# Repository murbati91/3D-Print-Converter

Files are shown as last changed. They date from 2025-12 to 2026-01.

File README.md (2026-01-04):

# 3D Print Converter

Convert CAD files directly to G-code and stream to your 3D printer via WiFi.





## Overview

3D Print Converter is an open-source solution that bridges the gap between CAD design and 3D printing. Upload DWG, DXF, PDF, or SVG files through a web interface, and the system automatically converts them to G-code and streams directly to your 3D printer.

### Key Features

- **Web-Based Interface** - Access via `http://3dconverter.local` from any device
- **Multiple Input Formats** - DWG, DGN, DXF, PDF, SVG, DAT
- **Multiple Output Formats** - STL, OBJ, STEP, G-code, 3MF
- **Direct Printer Control** - Stream G-code via UART with real-time progress
- **Standalone Operation** - ESP32 controller with TFT display
- **Low Cost** - ~$12 BOM for the controller hardware

## Architecture

```
┌─────────────────┐     ┌─────────────────┐     ┌─────────────────┐
│   Web Browser   │────▶│  ESP32-S3       │────▶│   3D Printer    │
│   (Any Device)  │     │  Controller     │     │   (UART)        │
└─────────────────┘     └────────┬────────┘     └─────────────────┘
                                 │
                                 ▼
                        ┌─────────────────┐
                        │  Python Server  │
                        │  (Conversion)   │
                        └─────────────────┘
```

## Components

| Component | Description |
|---|---|
| **Firmware** | ESP32-S3 Arduino code with web server, SD card, TFT display |
| **Server** | Python FastAPI conversion engine |
| **Portable App** | Standalone Windows application |
| **Enclosure** | 3D printable case (OpenSCAD + STL) |

## Quick Start

### 1. Hardware Setup

**Required Components:**
- ESP32-S3-WROOM-1 module
- 2.4" TFT ILI9341 or 1.3" ST7789 display
- MicroSD card slot
- 5V power supply

**Wiring:**
| Function | GPIO |
|---|---|
| TFT CS | 5 |
| TFT DC | 2 |
| TFT RST | 4 |
| SD CS | 12 |
| Printer TX | 17 |
| Printer RX | 16 |

### 2. Flash Firmware

```bash
# Install PlatformIO
pip install platformio

# Build and upload
cd 3d-print-converter/firmware
pio run -t upload
```

### 3. Run Conversion Server

```bash
# Install dependencies
cd 3d-print-converter/software
pip install -r requirements.txt

# Start server
python server.py --host 0.0.0.0 --port 8000
```

### 4. Connect and Print

1. Connect to ESP32 WiFi AP (`3DConverter`) or configure your network
2. Open `http://3dconverter.local` in your browser
3. Upload a CAD file
4. Click Convert → Print

## Conversion Pipeline

```
Input File (DWG/PDF/DXF/SVG)
    │
    ▼
┌───────────────────────────────┐
│  Stage 1: Format Detection    │
└───────────────────────────────┘
    │
    ▼
┌───────────────────────────────┐
│  Stage 2: DXF Normalization   │
│  - ODA Converter (DWG/DGN)    │
│  - Inkscape (PDF→SVG→DXF)     │
│  - ezdxf (native DXF)         │
└───────────────────────────────┘
    │
    ▼
┌───────────────────────────────┐
│  Stage 3: 2D→3D Conversion    │
│  - Profile extrusion          │
│  - Polygon generation         │
└───────────────────────────────┘
    │
    ▼
┌───────────────────────────────┐
│  Stage 4: Mesh Processing     │
│  - Repair & validation        │
│  - Scale & center             │
└───────────────────────────────┘
    │
    ▼
┌───────────────────────────────┐
│  Stage 5: G-code Generation   │
│  - PrusaSlicer (primary)      │
│  - Built-in slicer (fallback) │
└───────────────────────────────┘
    │
    ▼
Output (G-code) → Printer
```

## API Reference

### Endpoints

| Method | Endpoint | Description |
|---|---|---|
| GET | `/status` | System health and tool availability |
| POST | `/api/convert` | Synchronous conversion (streaming response) |
| POST | `/api/convert/async` | Async conversion (returns job ID) |
| GET | `/api/jobs/{id}` | Check job status |
| GET | `/api/jobs/{id}/download` | Download converted file |
| GET | `/api/formats` | List supported formats |

### Example Request

```bash
curl -X POST http://localhost:8000/api/convert \
  -F "file=@drawing.dxf" \
  -F "output_format=gcode" \
  -F "extrusion_height=10" \
  -F "layer_height=0.2"
```

## Configuration

### Conversion Settings

| Parameter | Default | Description |
|---|---|---|
| `extrusion_height` | 10.0 mm | Height for 2D→3D extrusion |
| `scale_factor` | 1.0 | Model scaling |
| `layer_height` | 0.2 mm | Slicer layer height |
| `nozzle_diameter` | 0.4 mm | Printer nozzle size |
| `print_speed` | 50 mm/s | Print movement speed |
| `infill_percentage` | 20% | Interior fill density |
| `bed_size` | 220x220x250 | Print volume (mm) |

### External Tools

For full format support, install these optional tools:

| Tool | Purpose | Required For |
|---|---|---|
| [ODA File Converter](https://www.opendesign.com/guestfiles/oda_file_converter) | DWG/DGN support | .dwg, .dgn files |
| [Inkscape](https://inkscape.org/) | PDF conversion | .pdf files |
| [FreeCAD](https://www.freecad.org/) | STEP export | .step output |
| [PrusaSlicer](https://www.prusa3d.com/prusaslicer/) | G-code generation | Better slicing quality |

## Hardware BOM

| Part | Quantity | Est. Cost |
|---|---|---|
| ESP32-S3-WROOM-1 | 1 | $4.00 |
| 2.4" TFT ILI9341 | 1 | $4.00 |
| MicroSD Module | 1 | $1.00 |
| AMS1117 3.3V Regulator | 1 | $0.50 |
| USB-C Connector | 1 | $0.50 |
| PCB + Misc | 1 | $2.50 |
| **Total** | | **~$12.50** |

## Project Structure

```
3d-print-converter/
├── firmware/
│   ├── src/main.cpp          # ESP32 firmware (1300+ lines)
│   └── platformio.ini        # Build configuration
│
├── software/
│   ├── converter_engine.py   # Conversion pipeline
│   ├── server.py             # FastAPI REST server
│   └── requirements.txt      # Python dependencies
│
├── enclosure/
│   ├── *.scad                # OpenSCAD source files
│   └── stl/                  # Ready-to-print STL files
│
├── portable-app/             # Standalone Windows app
│
└── build-exe/                # Windows executable
    └── dist/3D-Print-Converter.exe
```

## Troubleshooting

### ESP32 not connecting to WiFi
- Check credentials in web config portal
- Try AP mode: connect to `3DConverter` network, access `192.168.4.1`

### Conversion fails
- Verify Python server is running on port 8000
- Check server logs for missing tools (ODA, Inkscape)
- Ensure input file is valid (try opening in original CAD software)

### Printer not responding
- Verify UART wiring (TX→RX, RX→TX)
- Check baud rate matches printer (default: 115200)
- Ensure printer firmware supports standard G-code (Marlin compatible)

## Contributing

Contributions are welcome! Please feel free to submit issues and pull requests.

1. Fork the repository
2. Create your feature branch (`git checkout -b feature/amazing-feature`)
3. Commit your changes (`git commit -m 'Add amazing feature'`)
4. Push to the branch (`git push origin feature/amazing-feature`)
5. Open a Pull Request

## License

This project is licensed under the MIT License - see the [LICENSE](LICENSE) file for details.

## Acknowledgments

- [ezdxf](https://github.com/mozman/ezdxf) - DXF file handling
- [trimesh](https://github.com/mikedh/trimesh) - 3D mesh processing
- [PrusaSlicer](https://github.com/prusa3d/PrusaSlicer) - G-code generation
- [TFT_eSPI](https://github.com/Bodmer/TFT_eSPI) - ESP32 display driver

---

Made with :gear: by [murbati91](https://github.com/murbati91)

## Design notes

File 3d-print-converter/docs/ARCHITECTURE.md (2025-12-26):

# CAD-to-3D Print Converter System
## Complete Open-Source Solution

### System Overview

```
┌─────────────────────────────────────────────────────────────────────────────┐
│                        CAD-to-3D Print Converter                             │
├─────────────────────────────────────────────────────────────────────────────┤
│                                                                              │
│  ┌──────────────┐    ┌──────────────────┐    ┌──────────────────────────┐   │
│  │ INPUT FILES  │    │  CONVERSION      │    │  OUTPUT                  │   │
│  │              │    │  PIPELINE        │    │                          │   │
│  │ • .dwg       │───►│                  │───►│ • .stl (mesh)            │   │
│  │ • .dgn       │    │ Python + FreeCAD │    │ • .gcode (printer ready) │   │
│  │ • .dxf       │    │ + ODA Converter  │    │ • .3mf (modern format)   │   │
│  │ • .pdf       │    │                  │    │                          │   │
│  │ • .dat       │    └────────┬─────────┘    └──────────────────────────┘   │
│  └──────────────┘             │                                              │
│                               │                                              │
│  ┌────────────────────────────▼─────────────────────────────────────────┐   │
│  │                     HARDWARE CONTROLLER                               │   │
│  │  ┌─────────────┐  ┌─────────────┐  ┌─────────────┐  ┌─────────────┐  │   │
│  │  │   ESP32-S3  │  │  SD Card    │  │  OLED/TFT   │  │  3D Printer │  │   │
│  │  │   Main MCU  │──│  Storage    │──│  Display    │──│  Interface  │  │   │
│  │  └─────────────┘  └─────────────┘  └─────────────┘  └─────────────┘  │   │
│  └──────────────────────────────────────────────────────────────────────┘   │
│                                                                              │
└─────────────────────────────────────────────────────────────────────────────┘
```

---

## Part 1: Software Components (All Open Source)

### Required Software Stack

| Component | Purpose | License |
|---|---|---|
| **Python 3.10+** | Main scripting | PSF |
| **FreeCAD** | CAD operations, 3D modeling | LGPL |
| **ODA File Converter** | DWG/DGN to DXF | Free (proprietary but free) |
| **Inkscape** | PDF to SVG/DXF | GPL |
| **OpenSCAD** | Parametric 3D from scripts | GPL |
| **PrusaSlicer/Cura** | STL to G-code | AGPL/LGPL |
| **ezdxf** | Python DXF library | MIT |
| **trimesh** | Python 3D mesh library | MIT |
| **numpy-stl** | STL file handling | BSD |

### Conversion Flow

```
                    ┌─────────────────────────────────────────┐
                    │         FILE TYPE DETECTION              │
                    └──────────────────┬──────────────────────┘
                                       │
          ┌────────────────┬───────────┼───────────┬────────────────┐
          ▼                ▼           ▼           ▼                ▼
    ┌──────────┐    ┌──────────┐ ┌──────────┐ ┌──────────┐   ┌──────────┐
    │   DWG    │    │   DGN    │ │   DXF    │ │   PDF    │   │   DAT    │
    └────┬─────┘    └────┬─────┘ └────┬─────┘ └────┬─────┘   └────┬─────┘
         │               │            │            │              │
         ▼               ▼            │            ▼              ▼
    ┌──────────┐    ┌──────────┐     │      ┌──────────┐   ┌──────────┐
    │   ODA    │    │   ODA    │     │      │ Inkscape │   │  Parser  │
    │Converter │    │Converter │     │      │ PDF→SVG  │   │ (custom) │
    └────┬─────┘    └────┬─────┘     │      └────┬─────┘   └────┬─────┘
         │               │            │            │              │
         └───────────────┴────────────┼────────────┴──────────────┘
                                      │
                                      ▼
                              ┌──────────────┐
                              │   DXF/SVG    │
                              │  Normalized  │
                              └──────┬───────┘
                                     │
                                     ▼
                              ┌──────────────┐
                              │   FreeCAD    │
                              │  Processing  │
                              │              │
                              │ • 2D → 3D    │
                              │ • Extrusion  │
                              │ • Healing    │
                              └──────┬───────┘
                                     │
                                     ▼
                              ┌──────────────┐
                              │  STL/STEP    │
                              │   Output     │
                              └──────┬───────┘
                                     │
                                     ▼
                              ┌──────────────┐
                              │  PrusaSlicer │
                              │  STL→G-code  │
                              └──────┬───────┘
                                     │
                                     ▼
                              ┌──────────────┐
                              │   G-CODE     │
                              │  (Print)     │
                              └──────────────┘
```

---

## Part 2: Hardware Design

### ESP32-S3 Controller Board Features

- **MCU**: ESP32-S3-WROOM-1 (dual-core, 240MHz, WiFi, BLE)
- **Display**: 2.4" TFT or 1.3" OLED
- **Storage**: MicroSD card slot
- **Connectivity**: 
  - USB-C (file upload + power)
  - WiFi (web interface)
  - UART (3D printer serial)
- **Controls**: Rotary encoder + buttons
- **Power**: 5V USB or 12V from printer PSU

### PCB Block Diagram

```
                          ┌─────────────────────────────────────┐
                          │         3D Print Controller         │
                          │              PCB v1.0               │
                          └─────────────────────────────────────┘
                                           │
    ┌──────────────────────────────────────┼──────────────────────────────────┐
    │                                      │                                   │
    │  ┌─────────────┐              ┌──────┴──────┐              ┌──────────┐ │
    │  │   USB-C     │              │             │              │  SD Card │ │
    │  │  Connector  │──────────────│  ESP32-S3   │──────────────│   Slot   │ │
    │  │  (CH340C)   │              │  WROOM-1    │              │          │ │
    │  └─────────────┘              │             │              └──────────┘ │
    │                               │  ┌───────┐  │                           │
    │  ┌─────────────┐              │  │ PSRAM │  │              ┌──────────┐ │
    │  │   5V/3.3V   │              │  │  8MB  │  │              │  TFT/    │ │
    │  │  Regulator  │──────────────│  └───────┘  │──────────────│  OLED    │ │
    │  │  (AMS1117)  │              │             │   SPI        │ Display  │ │
    │  └─────────────┘              └──────┬──────┘              └──────────┘ │
    │                                      │                                   │
    │  ┌─────────────┐              ┌──────┴──────┐              ┌──────────┐ │
    │  │   Rotary    │              │    UART     │              │  Status  │ │
    │  │   Encoder   │──────────────│   Header    │──────────────│   LEDs   │ │
    │  │  + Button   │   GPIO       │ (to Printer)│    GPIO      │  RGB x3  │ │
    │  └─────────────┘              └─────────────┘              └──────────┘ │
    │                                                                          │
    └──────────────────────────────────────────────────────────────────────────┘
```

### Pin Assignments

| Function | ESP32-S3 Pin | Notes |
|---|---|---|
| USB D+ | GPIO19 | Native USB |
| USB D- | GPIO20 | Native USB |
| SD_CMD | GPIO35 | SD Card |
| SD_CLK | GPIO36 | SD Card |
| SD_D0 | GPIO37 | SD Card |
| TFT_CS | GPIO10 | Display |
| TFT_DC | GPIO9 | Display |
| TFT_RST | GPIO8 | Display |
| TFT_MOSI | GPIO11 | SPI |
| TFT_SCLK | GPIO12 | SPI |
| UART_TX | GPIO43 | To Printer |
| UART_RX | GPIO44 | From Printer |
| ENC_A | GPIO4 | Rotary Encoder |
| ENC_B | GPIO5 | Rotary Encoder |
| ENC_SW | GPIO6 | Encoder Button |
| LED_R | GPIO38 | Status LED |
| LED_G | GPIO39 | Status LED |
| LED_B | GPIO40 | Status LED |

---

## Part 3: System Modes

### Mode 1: Standalone (ESP32 Only)
- Upload files via WiFi web interface
- Basic conversion (DXF → STL extrusion)
- Send G-code directly to printer

### Mode 2: With Companion Server (Raspberry Pi / PC)
- Full conversion pipeline
- Complex 3D operations
- Web dashboard
- Queue management

### Mode 3: Cloud Hybrid
- Heavy conversion on cloud/server
- ESP32 handles file transfer + printer control
- Perfect for your ICC integration

---

## Bill of Materials (BOM)

| Component | Qty | Est. Cost | Source |
|---|-----|---|---|
| ESP32-S3-WROOM-1-N8R8 | 1 | $4.50 | AliExpress/LCSC |
| 2.4" TFT ILI9341 | 1 | $3.00 | AliExpress |
| MicroSD Card Slot | 1 | $0.30 | LCSC |
| USB-C Connector | 1 | $0.20 | LCSC |
| AMS1117-3.3V | 1 | $0.10 | LCSC |
| CH340C (USB-UART) | 1 | $0.50 | LCSC |
| Rotary Encoder | 1 | $0.50 | AliExpress |
| RGB LEDs (WS2812B) | 3 | $0.30 | LCSC |
| Capacitors/Resistors | Kit | $1.00 | LCSC |
| PCB (JLCPCB) | 5 | $2.00 | JLCPCB |
| **Total** | | **~$12.50** | |

---

## Getting Started

1. Install software dependencies (see `software/requirements.txt`)
2. Run the conversion server
3. Flash ESP32 firmware
4. Connect to WiFi and access web interface
5. Upload files and print!

---

## License

MIT License - Use freely for personal and commercial projects.

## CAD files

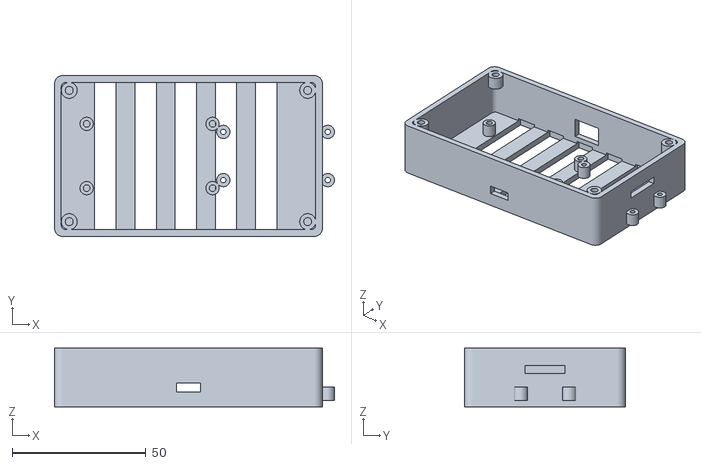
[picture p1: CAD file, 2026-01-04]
3d-print-converter/enclosure/stl/controller_base.stl
104.5 x 60.0 x 22.0

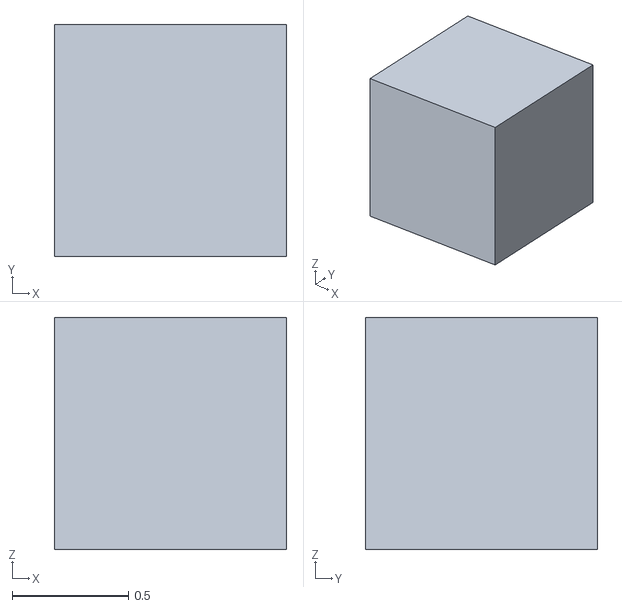
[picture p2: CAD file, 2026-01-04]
3d-print-converter/software/test_data/test_cube.stl
1.00 x 1.00 x 1.00

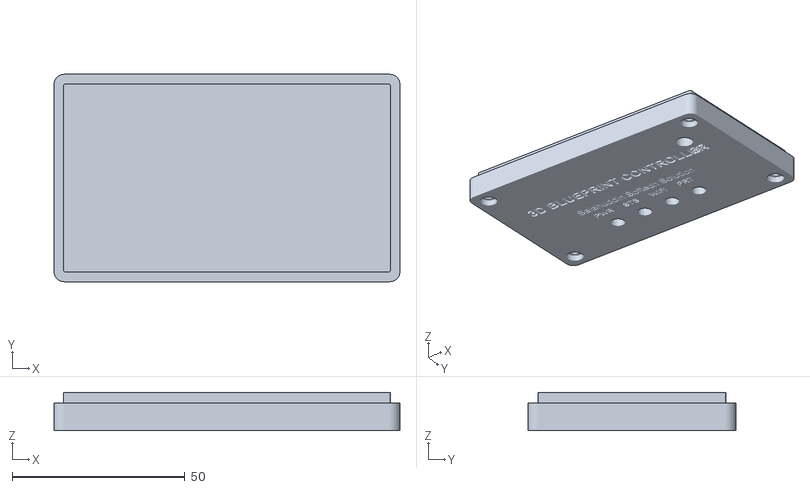
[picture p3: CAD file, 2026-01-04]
3d-print-converter/enclosure/stl/controller_lid.stl
100.0 x 60.0 x 11.0

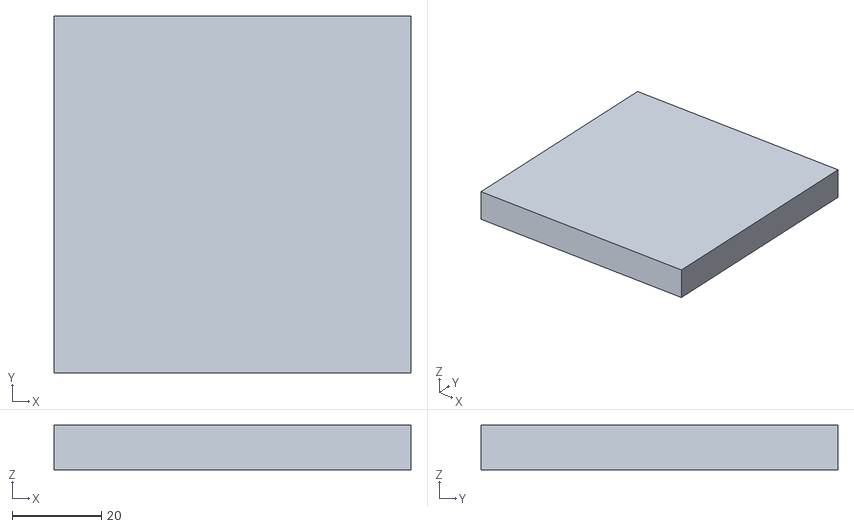
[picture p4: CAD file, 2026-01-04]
3d-print-converter/software/test_data/converted_square.stl
80.0 x 80.0 x 10.0

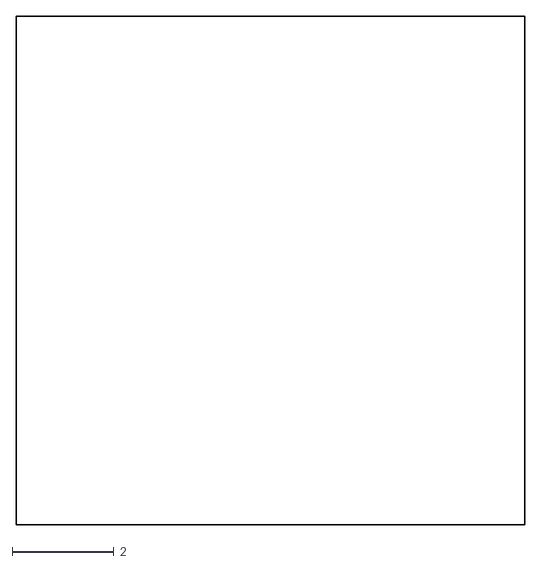
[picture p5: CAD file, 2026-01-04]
3d-print-converter/software/test_data/sample.dxf
10.0 x 10.0

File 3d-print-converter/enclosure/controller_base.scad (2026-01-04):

/*
 * 3D Blueprint Controller - BASE
 * Salahuddin Softech Solution
 *
 * Print this file for the enclosure base.
 * Export as STL: File > Export > Export as STL
 */

include <controller_enclosure.scad>

// Render base only
enclosure_base();

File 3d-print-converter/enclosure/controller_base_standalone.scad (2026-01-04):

/*
 * 3D Blueprint Controller - BASE (Standalone)
 * Salahuddin Softech Solution
 *
 * Print this file for the enclosure base.
 * Export as STL: File > Export > Export as STL
 */

// ==========================================
// PARAMETERS
// ==========================================

box_length = 100;
box_width = 60;
box_height = 30;
wall_thickness = 2.5;
corner_radius = 3;
base_height = 22;

esp32_length = 51;
esp32_width = 28;
esp32_standoff_height = 5;
esp32_hole_diameter = 2.5;

sd_module_length = 45;
sd_module_width = 24;
sd_module_standoff_height = 5;

usb_c_width = 9;
usb_c_height = 3.5;
sd_slot_width = 15;
sd_slot_height = 3;
uart_header_width = 12;
uart_header_height = 8;

screw_diameter = 3;
screw_head_diameter = 6;

// ==========================================
// MODULES
// ==========================================

module rounded_box(length, width, height, radius) {
    hull() {
        translate([radius, radius, 0])
            cylinder(r=radius, h=height, $fn=32);
        translate([length-radius, radius, 0])
            cylinder(r=radius, h=height, $fn=32);
        translate([radius, width-radius, 0])
            cylinder(r=radius, h=height, $fn=32);
        translate([length-radius, width-radius, 0])
            cylinder(r=radius, h=height, $fn=32);
    }
}

module screw_standoff(outer_d, inner_d, height) {
    difference() {
        cylinder(d=outer_d, h=height, $fn=24);
        cylinder(d=inner_d, h=height+1, $fn=24);
    }
}

// ==========================================
// BASE ENCLOSURE
// ==========================================

difference() {
    // Outer shell
    rounded_box(box_length, box_width, base_height, corner_radius);

    // Inner cavity
    translate([wall_thickness, wall_thickness, wall_thickness])
        rounded_box(
            box_length - 2*wall_thickness,
            box_width - 2*wall_thickness,
            base_height,
            corner_radius - wall_thickness/2
        );

    // USB-C port (front center)
    translate([box_length/2 - usb_c_width/2, -1, wall_thickness + 3])
        cube([usb_c_width, wall_thickness+2, usb_c_height]);

    // UART printer port (back)
    translate([box_length/2 - uart_header_width/2, box_width - wall_thickness - 1, wall_thickness + 3])
        cube([uart_header_width, wall_thickness+2, uart_header_height]);

    // SD card slot (right side)
    translate([box_length - wall_thickness - 1, box_width/2 - sd_slot_width/2, wall_thickness + esp32_standoff_height + 5])
        cube([wall_thickness+2, sd_slot_width, sd_slot_height]);

    // Ventilation slots (bottom)
    for (i = [0:4]) {
        translate([15 + i*15, wall_thickness/2, -1])
            cube([8, box_width - wall_thickness, wall_thickness+2]);
    }
}

// ESP32 mounting standoffs
esp32_x = 10;
esp32_y = (box_width - esp32_width) / 2;

standoff_positions = [
    [esp32_x + 2, esp32_y + 2],
    [esp32_x + esp32_length - 2, esp32_y + 2],
    [esp32_x + 2, esp32_y + esp32_width - 2],
    [esp32_x + esp32_length - 2, esp32_y + esp32_width - 2]
];

for (pos = standoff_positions) {
    translate([pos[0], pos[1], wall_thickness])
        screw_standoff(5, esp32_hole_diameter, esp32_standoff_height);
}

// SD module mounting standoffs
sd_x = 60;
sd_y = (box_width - sd_module_width) / 2;

sd_standoff_positions = [
    [sd_x + 3, sd_y + 3],
    [sd_x + sd_module_length - 3, sd_y + 3],
    [sd_x + 3, sd_y + sd_module_width - 3],
    [sd_x + sd_module_length - 3, sd_y + sd_module_width - 3]
];

for (pos = sd_standoff_positions) {
    translate([pos[0], pos[1], wall_thickness])
        screw_standoff(5, 2, sd_module_standoff_height);
}

// Lid mounting posts
lid_post_positions = [
    [wall_thickness + 3, wall_thickness + 3],
    [box_length - wall_thickness - 3, wall_thickness + 3],
    [wall_thickness + 3, box_width - wall_thickness - 3],
    [box_length - wall_thickness - 3, box_width - wall_thickness - 3]
];

for (pos = lid_post_positions) {
    translate([pos[0], pos[1], base_height - 5])
        screw_standoff(screw_head_diameter, screw_diameter, 5);
}

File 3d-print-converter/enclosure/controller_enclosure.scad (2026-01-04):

/*
 * 3D Blueprint Controller Enclosure
 * Salahuddin Softech Solution
 *
 * Housing for ESP32 + SD Card Module
 * Designed for FDM 3D printing (PLA/PETG)
 *
 * Print Settings:
 * - Layer Height: 0.2mm
 * - Infill: 20%
 * - Supports: Not required
 * - Walls: 3 perimeters
 */

// ==========================================
// PARAMETERS - Adjust as needed
// ==========================================

// Overall dimensions (mm)
box_length = 100;      // X dimension
box_width = 60;        // Y dimension
box_height = 30;       // Z dimension (base + lid)
wall_thickness = 2.5;
corner_radius = 3;

// Base/Lid split
base_height = 22;
lid_height = 8;

// ESP32 dimensions (ESP32-WROOM-32 DevKit)
esp32_length = 51;
esp32_width = 28;
esp32_standoff_height = 5;
esp32_hole_diameter = 2.5;

// SD Card module dimensions
sd_module_length = 45;
sd_module_width = 24;
sd_module_standoff_height = 5;

// LED hole dimensions
led_diameter = 5;  // 5mm LEDs
led_spacing = 12;
led_count = 4;

// Port dimensions
usb_c_width = 9;
usb_c_height = 3.5;
sd_slot_width = 15;
sd_slot_height = 3;
uart_header_width = 12;
uart_header_height = 8;

// Screw hole dimensions
screw_diameter = 3;
screw_head_diameter = 6;
screw_standoff_height = 3;

// Text emboss depth
text_depth = 0.8;

// Tolerance for fit
tolerance = 0.3;

// ==========================================
// MODULES
// ==========================================

// Rounded box module
module rounded_box(length, width, height, radius) {
    hull() {
        translate([radius, radius, 0])
            cylinder(r=radius, h=height, $fn=32);
        translate([length-radius, radius, 0])
            cylinder(r=radius, h=height, $fn=32);
        translate([radius, width-radius, 0])
            cylinder(r=radius, h=height, $fn=32);
        translate([length-radius, width-radius, 0])
            cylinder(r=radius, h=height, $fn=32);
    }
}

// Screw standoff
module screw_standoff(outer_d, inner_d, height) {
    difference() {
        cylinder(d=outer_d, h=height, $fn=24);
        cylinder(d=inner_d, h=height+1, $fn=24);
    }
}

// LED holder
module led_holder(diameter, depth) {
    union() {
        // Main LED hole
        cylinder(d=diameter, h=depth+1, $fn=24);
        // Flange for LED retention
        translate([0, 0, depth-1])
            cylinder(d=diameter+2, h=2, $fn=24);
    }
}

// ==========================================
// BASE ENCLOSURE
// ==========================================

module enclosure_base() {
    difference() {
        // Outer shell
        rounded_box(box_length, box_width, base_height, corner_radius);

        // Inner cavity
        translate([wall_thickness, wall_thickness, wall_thickness])
            rounded_box(
                box_length - 2*wall_thickness,
                box_width - 2*wall_thickness,
                base_height,
                corner_radius - wall_thickness/2
            );

        // USB-C port (front center)
        translate([box_length/2 - usb_c_width/2, -1, wall_thickness + 3])
            cube([usb_c_width, wall_thickness+2, usb_c_height]);

        // UART printer port (back)
        translate([box_length/2 - uart_header_width/2, box_width - wall_thickness - 1, wall_thickness + 3])
            cube([uart_header_width, wall_thickness+2, uart_header_height]);

        // SD card slot (right side)
        translate([box_length - wall_thickness - 1, box_width/2 - sd_slot_width/2, wall_thickness + esp32_standoff_height + 5])
            cube([wall_thickness+2, sd_slot_width, sd_slot_height]);

        // Ventilation slots (bottom)
        for (i = [0:4]) {
            translate([15 + i*15, wall_thickness/2, -1])
                cube([8, box_width - wall_thickness, wall_thickness+2]);
        }
    }

    // ESP32 mounting standoffs (4 corners)
    esp32_x = 10;
    esp32_y = (box_width - esp32_width) / 2;

    // Standoff positions for ESP32
    standoff_positions = [
        [esp32_x + 2, esp32_y + 2],
        [esp32_x + esp32_length - 2, esp32_y + 2],
        [esp32_x + 2, esp32_y + esp32_width - 2],
        [esp32_x + esp32_length - 2, esp32_y + esp32_width - 2]
    ];

    for (pos = standoff_positions) {
        translate([pos[0], pos[1], wall_thickness])
            screw_standoff(5, esp32_hole_diameter, esp32_standoff_height);
    }

    // SD module mounting standoffs
    sd_x = 60;
    sd_y = (box_width - sd_module_width) / 2;

    sd_standoff_positions = [
        [sd_x + 3, sd_y + 3],
        [sd_x + sd_module_length - 3, sd_y + 3],
        [sd_x + 3, sd_y + sd_module_width - 3],
        [sd_x + sd_module_length - 3, sd_y + sd_module_width - 3]
    ];

    for (pos = sd_standoff_positions) {
        translate([pos[0], pos[1], wall_thickness])
            screw_standoff(5, 2, sd_module_standoff_height);
    }

    // Lid mounting posts (4 corners)
    lid_post_positions = [
        [wall_thickness + 3, wall_thickness + 3],
        [box_length - wall_thickness - 3, wall_thickness + 3],
        [wall_thickness + 3, box_width - wall_thickness - 3],
        [box_length - wall_thickness - 3, box_width - wall_thickness - 3]
    ];

    for (pos = lid_post_positions) {
        translate([pos[0], pos[1], base_height - 5])
            screw_standoff(screw_head_diameter, screw_diameter, 5);
    }
}

// ==========================================
// LID
// ==========================================

module enclosure_lid() {
    difference() {
        union() {
            // Main lid body
            rounded_box(box_length, box_width, lid_height, corner_radius);

            // Inner lip for secure fit
            translate([wall_thickness + tolerance, wall_thickness + tolerance, -3])
                rounded_box(
                    box_length - 2*(wall_thickness + tolerance),
                    box_width - 2*(wall_thickness + tolerance),
                    3,
                    corner_radius - wall_thickness
                );
        }

        // LED holes (4 LEDs in a row)
        led_start_x = (box_length - (led_count-1) * led_spacing) / 2;
        led_y = 15;

        for (i = [0:led_count-1]) {
            translate([led_start_x + i * led_spacing, led_y, -1])
                led_holder(led_diameter, lid_height + 2);
        }

        // Reset button hole
        translate([box_length - 15, box_width - 15, -1])
            cylinder(d=6, h=lid_height + 2, $fn=24);

        // Screw holes for lid attachment
        lid_post_positions = [
            [wall_thickness + 3, wall_thickness + 3],
            [box_length - wall_thickness - 3, wall_thickness + 3],
            [wall_thickness + 3, box_width - wall_thickness - 3],
            [box_length - wall_thickness - 3, box_width - wall_thickness - 3]
        ];

        for (pos = lid_post_positions) {
            translate([pos[0], pos[1], -1])
                cylinder(d=screw_diameter + 0.5, h=lid_height + 5, $fn=24);
            // Countersink for screw head
            translate([pos[0], pos[1], lid_height - 2])
                cylinder(d=screw_head_diameter, h=3, $fn=24);
        }

        // Branding text emboss (top surface)
        translate([box_length/2, box_width/2 + 8, lid_height - text_depth])
            linear_extrude(text_depth + 1)
                text("3D BLUEPRINT CONTROLLER",
                     size=4,
                     font="Arial:style=Bold",
                     halign="center",
                     valign="center");

        translate([box_length/2, box_width/2 - 2, lid_height - text_depth])
            linear_extrude(text_depth + 1)
                text("Salahuddin Softech Solution",
                     size=3,
                     font="Arial",
                     halign="center",
                     valign="center");

        // LED labels
        led_labels = ["PWR", "STS", "WiFi", "PRT"];
        for (i = [0:led_count-1]) {
            translate([led_start_x + i * led_spacing, led_y + 8, lid_height - text_depth])
                linear_extrude(text_depth + 1)
                    text(led_labels[i],
                         size=2.5,
                         font="Arial:style=Bold",
                         halign="center",
                         valign="center");
        }

        // Reset label
        translate([box_length - 15, box_width - 22, lid_height - text_depth])
            linear_extrude(text_depth + 1)
                text("RST",
                     size=2.5,
                     font="Arial:style=Bold",
                     halign="center",
                     valign="center");
    }
}

// ==========================================
// PORT LABELS (for base)
// ==========================================

module port_labels() {
    // USB-C label
    translate([box_length/2, -0.5, base_height - 5])
        rotate([90, 0, 0])
            linear_extrude(1)
                text("USB-C", size=3, font="Arial:style=Bold", halign="center");
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

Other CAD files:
3d-print-converter/enclosure/controller_lid.scad

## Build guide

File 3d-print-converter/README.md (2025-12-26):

# 🖨️ CAD-to-3D Print Converter

> **Open-source solution for converting DWG, DGN, DXF, PDF to 3D printable formats**





## 🎯 Features

- **Multi-format support**: DWG, DGN, DXF, PDF, DAT, SVG
- **Output formats**: STL, OBJ, STEP, G-code, 3MF
- **Hardware controller**: ESP32-S3 based PCB design
- **Web interface**: Upload files via WiFi
- **Direct printing**: Stream G-code to printer
- **100% Open Source**: MIT licensed

## 📁 Project Structure

```
3d-print-converter/
├── software/              # Python conversion engine
│   ├── converter_engine.py    # Main conversion library
│   ├── server.py             # FastAPI REST server
│   └── requirements.txt      # Python dependencies
│
├── firmware/              # ESP32-S3 firmware
│   ├── src/main.cpp          # Main firmware code
│   └── platformio.ini        # PlatformIO config
│
├── hardware/              # PCB design files
│   └── 3d_print_controller.kicad_sch
│
├── docs/                  # Documentation
│   └── ARCHITECTURE.md       # System architecture
│
├── install.sh            # Installation script
└── README.md             # This file
```

## 🚀 Quick Start

### Option 1: Software Only (PC/Server)

```bash
# Clone the repository
git clone https://github.com/your-repo/3d-print-converter.git
cd 3d-print-converter

# Run installation script
chmod +x install.sh
./install.sh

# Start the server
source venv/bin/activate
python software/server.py
```

Access the API at: `http://localhost:8000`

### Option 2: Full System (ESP32 + Server)

1. **Install software** (as above)
2. **Flash ESP32 firmware**:
   ```bash
   cd firmware
   pio run -t upload
   ```
3. **Configure WiFi** via AP mode (192.168.4.1)
4. **Set companion server URL** in web interface

## 📖 API Usage

### Convert a File

```bash
# Single file conversion
curl -X POST "http://localhost:8000/api/convert" \
  -F "file=@drawing.dwg" \
  -o output.gcode

# With parameters
curl -X POST "http://localhost:8000/api/convert?output_format=stl&extrusion_height=5" \
  -F "file=@drawing.dxf" \
  -o output.stl
```

### Python Client

```python
import requests

# Convert file
with open('drawing.dwg', 'rb') as f:
    response = requests.post(
        'http://localhost:8000/api/convert',
        files={'file': f},
        params={'output_format': 'gcode'}
    )

# Save result
with open('output.gcode', 'wb') as f:
    f.write(response.content)
```

## 🔧 Hardware Build

### Bill of Materials (~$12.50)

| Component | Qty | Est. Cost |
|---|-----|---|
| ESP32-S3-WROOM-1-N8R8 | 1 | $4.50 |
| 2.4" TFT ILI9341 | 1 | $3.00 |
| MicroSD Card Slot | 1 | $0.30 |
| USB-C Connector | 1 | $0.20 |
| AMS1117-3.3V | 1 | $0.10 |
| CH340C | 1 | $0.50 |
| Rotary Encoder | 1 | $0.50 |
| Misc (caps, resistors) | - | $1.00 |
| PCB (JLCPCB x5) | 5 | $2.00 |

### PCB Manufacturing

1. Open `hardware/3d_print_controller.kicad_sch` in KiCad
2. Generate Gerber files
3. Upload to JLCPCB/PCBWay
4. Select 2-layer, 1.6mm thickness

## 🛠️ Conversion Pipeline

```
┌─────────────┐    ┌──────────────┐    ┌─────────────┐    ┌──────────────┐
│ Input File  │───►│ ODA/Inkscape │───►│  FreeCAD    │───►│ PrusaSlicer  │
│ DWG/DGN/PDF │    │  → DXF       │    │  → STL      │    │  → G-code    │
└─────────────┘    └──────────────┘    └─────────────┘    └──────────────┘
```

## 📦 Dependencies

### Required (automatically installed)

- **Python 3.10+**
- **ezdxf** - DXF file handling
- **trimesh** - 3D mesh operations
- **FastAPI** - REST API server
- **numpy-stl** - STL file handling

### External Tools

| Tool | Purpose | Installation |
|---|---|---|
| FreeCAD | CAD processing | `apt install freecad` |
| ODA Converter | DWG/DGN support | [Download](https://www.opendesign.com/guestfiles/oda_file_converter) |
| Inkscape | PDF/SVG conversion | `apt install inkscape` |
| PrusaSlicer | G-code generation | [Download](https://www.prusa3d.com/prusaslicer/) |
| OpenSCAD | Parametric modeling | `apt install openscad` |

## 🌐 Integration with Your Infrastructure

### With Infrastructure Control Center (ICC)

```python
# Add to ICC monitoring
from icc_client import ICCClient

icc = ICCClient('icc.bahrain-ai.com')
icc.register_service(
    name='3d-converter',
    url='http://converter-server:8000',
    health_check='/status'
)
```

### Docker Deployment

```dockerfile
FROM python:3.11-slim

RUN apt-get update && apt-get install -y \
    freecad inkscape openscad

WORKDIR /app
COPY . .
RUN pip install -r software/requirements.txt

EXPOSE 8000
CMD ["python", "software/server.py"]
```

## 🐛 Troubleshooting

### ODA Converter not found
```bash
# Check if installed
which ODAFileConverter

# If missing, download from:
# https://www.opendesign.com/guestfiles/oda_file_converter
```

### ESP32 won't flash
```bash
# Hold BOOT button while connecting USB
# Then release and run:
pio run -t upload
```

### Conversion fails
```bash
# Check tool availability
curl http://localhost:8000/api/formats

# Review logs
tail -f /var/log/3d-converter.log
```

## 🤝 Contributing

1. Fork the repository
2. Create feature branch (`git checkout -b feature/amazing`)
3. Commit changes (`git commit -m 'Add amazing feature'`)
4. Push to branch (`git push origin feature/amazing`)
5. Open Pull Request

## 📄 License

MIT License - see [LICENSE](LICENSE) file.

## 🙏 Acknowledgments

- [ODA (Open Design Alliance)](https://www.opendesign.com/) for DWG/DGN support
- [FreeCAD](https://www.freecad.org/) for CAD processing
- [PrusaSlicer](https://www.prusa3d.com/prusaslicer/) for G-code generation
- [ESP32](https://www.espressif.com/) community

---

**Made with ❤️ by Tech Sierra Solutions**

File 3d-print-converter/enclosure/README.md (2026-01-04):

# 3D Blueprint Controller Enclosure

**Salahuddin Softech Solution**

Professional 3D printable enclosure for ESP32 + SD Card Module assembly.

## Files

### STL Files (Ready to Print)
- `stl/controller_base.stl` - Enclosure base (461 KB)
- `stl/controller_lid.stl` - Enclosure lid with branding (1.5 MB)

### OpenSCAD Source Files
- `controller_enclosure.scad` - Main design with all modules
- `controller_base_standalone.scad` - Base only (for modification)
- `controller_lid.scad` - Lid only (for modification)

### Documentation
- `ASSEMBLY_INSTRUCTIONS.md` - Complete assembly guide with wiring diagrams

### Utilities
- `export_stl.bat` - Batch script to regenerate STL files

## Quick Print Settings

| Parameter | Value |
|---|---|
| Material | PLA (Black/Dark Gray) |
| Layer Height | 0.2mm |
| Infill | 20% |
| Supports | Not required |
| Walls | 3 perimeters |
| Print Time | ~80 min total |

## Dimensions

- **Overall**: 100mm x 60mm x 30mm
- **Wall Thickness**: 2.5mm
- **Weight**: ~35g (both parts)

## Features

- 4 LED indicator holes (5mm)
- USB-C power port
- SD card access slot
- UART printer port
- Reset button access
- Ventilation slots
- Professional branding embossed

## Print Order

1. Print `controller_base.stl` upright
2. Print `controller_lid.stl` upside-down (as exported)
3. No supports needed for either part

---

*Salahuddin Softech Solution*

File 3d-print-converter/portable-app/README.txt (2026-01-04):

============================================
   3D Print Converter - Portable App
   by Tech Sierra Solutions
============================================

Convert CAD files (PDF, DWG, DXF, SVG) to
G-code for 3D printing.

REQUIREMENTS:
-------------
1. Windows 10/11
2. Python 3.11 or higher
3. Internet (for first-time setup only)

OPTIONAL (for full conversion support):
- Inkscape (PDF conversion)
- PrusaSlicer (G-code generation)
- ODA File Converter (DWG files)

FIRST TIME SETUP:
-----------------
1. Install Python from https://python.org
   (Check "Add Python to PATH"!)

2. Run "Install-Dependencies.bat"

3. Run "Start-3D-Converter.bat"

HOW TO USE:
-----------
1. Double-click "Start-3D-Converter.bat"
2. The converter app opens in your browser
3. Drag & drop files or click to upload
4. Adjust settings (scale, format, etc.)
5. Converted files download automatically

SUPPORTED FORMATS:
------------------
Input:  PDF, DWG, DXF, SVG, DAT
Output: G-code, STL, OBJ, 3MF

TROUBLESHOOTING:
----------------
- "Python not found": Install Python and
  check "Add to PATH"

- "Connection failed": Make sure the server
  window is running (minimize, don't close)

- "Conversion failed": Check if required
  tools (Inkscape, PrusaSlicer) are installed

SUPPORT:
--------
Tech Sierra Solutions
https://techsierrasolutions.com

============================================

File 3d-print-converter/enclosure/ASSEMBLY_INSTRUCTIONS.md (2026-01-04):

# 3D Blueprint Controller - Assembly Instructions

**Salahuddin Softech Solution**

---

## Components Required

### Electronics
| Component | Quantity | Notes |
|---|---|---|
| ESP32-WROOM-32 DevKit | 1 | 30-pin version |
| MicroSD Card Module | 1 | SPI interface |
| 5mm LEDs | 4 | Colors: Green (PWR), Blue (STS), Yellow (WiFi), Red (PRT) |
| 220Ω Resistors | 4 | For LED current limiting |
| Tactile Push Button | 1 | 6x6mm, for reset |
| Dupont Wires | ~15 | Female-to-Female |
| MicroSD Card | 1 | 32GB FAT32 formatted |

### Hardware
| Item | Quantity | Notes |
|---|---|---|
| M3x8mm Screws | 4 | For lid attachment |
| M2x5mm Self-tapping | 8 | For PCB mounting |
| USB-C Cable | 1 | For power |
| Printer Serial Cable | 1 | USB-to-Serial or direct |

### Printed Parts
| File | Material | Settings |
|---|---|---|
| controller_base.stl | PLA (Black) | 0.2mm, 20% infill |
| controller_lid.stl | PLA (Black) | 0.2mm, 20% infill |

---

## Wiring Diagram

### ESP32 Pin Connections

```
                    ESP32 DevKit (30-pin)
                    ┌─────────────────────┐
                    │      [USB-C]        │
                    │   ○              ○   │
              EN ───│ ○              ○ │─── GPIO23
         GPIO36 ───│ ○              ○ │─── GPIO22
         GPIO39 ───│ ○              ○ │─── GPIO1  (TX)
         GPIO34 ───│ ○              ○ │─── GPIO3  (RX)
         GPIO35 ───│ ○              ○ │─── GPIO21
         GPIO32 ───│ ○              ○ │─── GND
         GPIO33 ───│ ○              ○ │─── GPIO19
         GPIO25 ───│ ○              ○ │─── GPIO18
         GPIO26 ───│ ○              ○ │─── GPIO5
  SD_MOSI GPIO27 ◄──│ ●              ○ │─── GPIO17 ──► PRINTER TX
  SD_CLK  GPIO14 ◄──│ ●              ○ │─── GPIO16 ──► PRINTER RX
    SD_CS GPIO12 ◄──│ ●              ○ │─── GPIO4
  SD_MISO GPIO13 ◄──│ ●              ○ │─── GPIO0
             GND ───│ ●              ○ │─── GPIO2
             VIN ───│ ○              ○ │─── GPIO15
                    │   ○              ○   │
                    └─────────────────────┘

        ● = SD Card Module connections (LEFT SIDE)
        ► = Printer Serial connections
```

### SD Card Module Wiring

```
    SD Card Module              ESP32
    ┌────────────┐
    │  ┌─────┐   │
    │  │ SD  │   │    Wire Colors (suggested):
    │  │Card │   │
    │  │ ──► │   │    Orange ─── CS (D12)
    │  └─────┘   │    Yellow ─── MOSI (D27)
    │            │    Green ──── CLK (D14)
    │ CS ●───────│────────────► GPIO12
    │ SCK●───────│────────────► GPIO14
    │MOSI●───────│────────────► GPIO27
    │MISO●───────│────────────► GPIO13
    │ VCC●───────│────────────► 3.3V
    │ GND●───────│────────────► GND
    └────────────┘
```

### LED Wiring

```
    From ESP32 GPIO pins to LEDs in lid:

    PWR LED (Green):  3.3V ──[220Ω]──► LED+ ──► LED- ──► GND
                      (Always on when powered)

    STS LED (Blue):   GPIO2 ──[220Ω]──► LED+ ──► LED- ──► GND

    WiFi LED (Yellow): GPIO15 ──[220Ω]──► LED+ ──► LED- ──► GND

    PRT LED (Red):    GPIO4 ──[220Ω]──► LED+ ──► LED- ──► GND
```

### Printer Connection

```
    ESP32                      3D Printer (Creality K1C)
    ┌───────┐                  ┌────────────┐
    │GPIO17 │────► TX ─────────│ RX (Serial)│
    │GPIO16 │◄──── RX ─────────│ TX (Serial)│
    │  GND  │──────────────────│    GND     │
    └───────┘                  └────────────┘

    Baud Rate: 115200
    Settings: 8N1 (8 data bits, no parity, 1 stop bit)
```

---

## Assembly Steps

### Step 1: Print Enclosure (60-90 minutes)

1. **Base**: Load `controller_base.stl` in slicer
   - Layer height: 0.2mm
   - Infill: 20%
   - No supports needed
   - Print time: ~45 minutes

2. **Lid**: Load `controller_lid.stl` in slicer
   - Print upside-down (as oriented in STL)
   - Layer height: 0.2mm
   - Infill: 20%
   - No supports needed
   - Print time: ~35 minutes

### Step 2: Prepare Electronics (10 minutes)

1. **Format SD Card**
   - Insert SD card into computer
   - Format as FAT32
   - Eject safely

2. **Flash ESP32**
   - Connect ESP32 via USB
   - Upload firmware using PlatformIO
   - Verify serial output shows "SD: false" (not connected yet)

### Step 3: Mount ESP32 (5 minutes)

```
    Enclosure Base (top view)
    ┌────────────────────────────────────────────────────────────────┐
    │                                                                │
    │     ┌──────────────────────────────┐                          │
    │     │         ESP32                │    ┌──────────────────┐  │
    │     │     ┌──────────────┐         │    │   SD Card        │  │
    │     │     │              │         │    │   Module         │  │
    │     │     │    USB-C     │         │    │   ┌────┐        │  │
    │     │     │              │         │    │   │ SD │        │  │
    │     │     └──────────────┘         │    │   └────┘        │  │
    │     │    (faces front port)        │    │                  │  │
    │     └──────────────────────────────┘    └──────────────────┘  │
    │           ↑                                    ↑              │
    │      Standoffs                            Standoffs           │
    │                                                                │
    │    [USB-C PORT]                              [SD SLOT]        │
    └────────────────────────────────────────────────────────────────┘
                        [PRINTER PORT]
```

1. Place ESP32 on mounting standoffs
2. USB-C port should face the front opening
3. Use M2 self-tapping screws (optional - friction fit works)

### Step 4: Mount SD Card Module (5 minutes)

1. Place SD card module on right-side standoffs
2. Card slot should align with side opening
3. Secure with M2 screws (optional)

### Step 5: Wire SD Card Module (10 minutes)

Connect using Dupont wires:

| SD Module | ESP32 | Wire Color |
|---|---|---|
| CS | GPIO12 (D12) | Orange |
| MOSI | GPIO27 (D27) | Yellow |
| MISO | GPIO13 (D13) | Green |
| SCK | GPIO14 (D14) | Blue |
| VCC | 3.3V | Red |
| GND | GND | Black |

**IMPORTANT**: Use LEFT side of ESP32 (HSPI pins)!

### Step 6: Wire LEDs (15 minutes)

1. Solder 220Ω resistor to each LED's positive (longer) leg
2. Thread LED leads through lid holes from inside
3. Connect wires:

| LED | Function | ESP32 Pin | Notes |
|-----|---|---|---|
| Green | Power | 3.3V | Direct (always on) |
| Blue | Status | GPIO2 | With resistor |
| Yellow | WiFi | GPIO15 | With resistor |
| Red | Printer | GPIO4 | With resistor |

All LED negative legs connect to GND.

### Step 7: Install Reset Button (5 minutes)

1. Insert tactile button into lid hole
2. Connect one leg to ESP32 EN pin
3. Connect opposite leg to GND

### Step 8: Final Assembly (5 minutes)

1. Insert formatted SD card into module
2. Carefully place wired lid onto base
3. Ensure no wires are pinched
4. Secure with 4x M3 screws in corners

### Step 9: Test (5 minutes)

1. Connect USB-C power
2. Verify LEDs:
   - Green (PWR): ON immediately
   - Yellow (WiFi): Flashing during connection
   - Blue (STS): Activity indicator

3. Connect to http://3dconverter.local or http://blueprint.local
4. Check status shows `{"sd": true}`

---

## Troubleshooting

### SD Card Not Detected
- Verify wiring (CS=D12, MOSI=D27, MISO=D13, CLK=D14)
- Ensure SD card is FAT32 formatted
- Check SD card is fully inserted (click sound)
- Press RST button to reinitialize

### WiFi Not Connecting
- Check if hotspot "Blueprint-Setup" appears
- Connect and configure at 192.168.4.1
- Ensure 2.4GHz network (not 5GHz)

### Printer Not Responding
- Verify TX/RX connections (GPIO16/17)
- Check baud rate is 115200
- Ensure printer is powered on

### LEDs Not Working
- Check resistor values (220Ω)
- Verify LED polarity (longer leg = positive)
- Test GPIO pins with multimeter

---

## Final Checklist

- [ ] Base printed and cleaned
- [ ] Lid printed and cleaned
- [ ] ESP32 mounted and secured
- [ ] SD card module mounted
- [ ] All wiring connected correctly
- [ ] LEDs installed in lid
- [ ] Reset button installed
- [ ] SD card inserted (FAT32)
- [ ] Lid secured with screws
- [ ] USB-C power connected
- [ ] Status page shows SD: true
- [ ] WiFi connected
- [ ] Test file conversion works

---

## Support

**Email**: support@salahuddinss.com
**Web**: www.salahuddinss.com

---

*Salahuddin Softech Solution - "From Blueprint to Model in Minutes"*

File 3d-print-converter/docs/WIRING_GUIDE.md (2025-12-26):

# Wiring Guide: ESP32-WROOM-32 with Screw Terminals

## Your Board
- **Model**: ESP32 N4R2 (4MB Flash, 2MB PSRAM)
- **Features**: WiFi + Bluetooth, Screw terminals for easy connections

---

## Pin Mapping Diagram

```
                    ┌─────────────────────────────────────┐
                    │      ESP32 WROOM-32 DevKit          │
                    │       with Screw Terminals          │
                    │                                     │
                    │    ┌─────────────────────────┐      │
                    │    │   ESP32-WROOM-32 N4R2   │      │
                    │    │    WiFi+BT SOC INSIDE   │      │
                    │    └─────────────────────────┘      │
                    │                                     │
    LEFT TERMINALS  │    [EN]  [BOOT]      [USB]         │  RIGHT TERMINALS
    ═══════════════ │                                     │ ════════════════
                    │                                     │
    3V3 ───────────○│                                     │○─────────── VIN (5V)
    GND ───────────○│                                     │○─────────── GND
    D15 (TFT_BL)───○│                                     │○─────────── D13 (SD_MISO)
    D2  (TFT_DC)───○│                                     │○─────────── D12 (SD_CS)
    D4  (TFT_RST)──○│                                     │○─────────── D14 (SD_CLK)
    RX2 (GPIO16)───○│                                     │○─────────── D27 (SD_MOSI)
    TX2 (GPIO17)───○│   ← Printer UART                    │○─────────── D26 (ENC_SW)
    D5  (TFT_CS)───○│                                     │○─────────── D25 (ENC_B)
    D18 (TFT_SCK)──○│                                     │○─────────── D33 (ENC_A)
    D19 (TFT_MISO)─○│                                     │○─────────── D32 (LED_DATA)
    D21 (SDA)──────○│                                     │○─────────── D35 (input only)
    D3  (RX0)──────○│   ← Programming                     │○─────────── D34 (input only)
    D1  (TX0)──────○│   ← Programming                     │○─────────── VN
    D22 (SCL)──────○│                                     │○─────────── VP
    D23 (TFT_MOSI)─○│                                     │○─────────── EN
                    │                                     │
                    └─────────────────────────────────────┘
```

---

## Component Connections

### 1️⃣ TFT Display (ILI9341 2.4" SPI)

| TFT Pin | ESP32 Pin | Screw Terminal |
|---|---|---|
| VCC | 3V3 | Left: 3V3 |
| GND | GND | Left: GND |
| CS | GPIO5 | Left: D5 |
| RESET | GPIO4 | Left: D4 |
| DC/RS | GPIO2 | Left: D2 |
| MOSI | GPIO23 | Left: D23 |
| SCK | GPIO18 | Left: D18 |
| LED | GPIO15 | Left: D15 |
| MISO | GPIO19 | Left: D19 |

```
TFT Display           ESP32 Screw Terminal
┌──────────┐          ┌─────────────────┐
│ VCC    ──┼──────────┤ 3V3             │
│ GND    ──┼──────────┤ GND             │
│ CS     ──┼──────────┤ D5              │
│ RESET  ──┼──────────┤ D4              │
│ DC     ──┼──────────┤ D2              │
│ MOSI   ──┼──────────┤ D23             │
│ SCK    ──┼──────────┤ D18             │
│ LED    ──┼──────────┤ D15             │
│ MISO   ──┼──────────┤ D19             │
└──────────┘          └─────────────────┘
```

---

### 2️⃣ MicroSD Card Module

| SD Pin  | ESP32 Pin | Screw Terminal |
|---|---|---|
| VCC | 3V3 | Left: 3V3 |
| GND | GND | Right: GND |
| CS | GPIO12 | Right: D12 |
| MOSI | GPIO27 | Right: D27 |
| SCK | GPIO14 | Right: D14 |
| MISO | GPIO13 | Right: D13 |

```
SD Card Module        ESP32 Screw Terminal
┌──────────┐          ┌─────────────────┐
│ VCC    ──┼──────────┤ 3V3 (Left)      │
│ GND    ──┼──────────┤ GND (Right)     │
│ CS     ──┼──────────┤ D12             │
│ MOSI   ──┼──────────┤ D27             │
│ SCK    ──┼──────────┤ D14             │
│ MISO   ──┼──────────┤ D13             │
└──────────┘          └─────────────────┘
```

---

### 3️⃣ 3D Printer UART Connection

| Printer  | ESP32 Pin | Screw Terminal |
|---|---|---|
| RX | TX2 (17)  | Left: TX2 |
| TX | RX2 (16)  | Left: RX2 |
| GND | GND | Any GND |

**⚠️ Important**: Cross TX/RX connections!
- ESP32 TX → Printer RX
- ESP32 RX → Printer TX

```
3D Printer Board      ESP32 Screw Terminal
┌──────────┐          ┌─────────────────┐
│ RX     ──┼──────────┤ TX2 (GPIO17)    │
│ TX     ──┼──────────┤ RX2 (GPIO16)    │
│ GND    ──┼──────────┤ GND             │
└──────────┘          └─────────────────┘
```

**Common Printer Boards:**
- Creality 4.2.x: Look for EXP1 or TFT connector
- SKR Mini: TFT header
- Marlin-based: Usually has serial header

---

### 4️⃣ Rotary Encoder (Optional)

| Encoder | ESP32 Pin | Screw Terminal |
|---|---|---|
| GND | GND | Right: GND |
| + | 3V3 | Left: 3V3 |
| A (CLK) | GPIO33 | Right: D33 |
| B (DT)  | GPIO25 | Right: D25 |
| SW | GPIO26 | Right: D26 |

```
Rotary Encoder        ESP32 Screw Terminal
┌──────────┐          ┌─────────────────┐
│ GND    ──┼──────────┤ GND             │
│ +      ──┼──────────┤ 3V3             │
│ CLK    ──┼──────────┤ D33             │
│ DT     ──┼──────────┤ D25             │
│ SW     ──┼──────────┤ D26             │
└──────────┘          └─────────────────┘
```

---

### 5️⃣ WS2812B LED Strip (Optional)

| LED | ESP32 Pin | Screw Terminal |
|---|---|---|
| VCC | VIN (5V)  | Right: VIN |
| GND | GND | Right: GND |
| DIN | GPIO32 | Right: D32 |

---

## Complete Wiring Diagram

```
┌─────────────────────────────────────────────────────────────────────────────┐
│                          COMPLETE SYSTEM WIRING                              │
└─────────────────────────────────────────────────────────────────────────────┘

                    ┌──────────────────────────────────┐
                    │         2.4" TFT DISPLAY         │
                    │          (ILI9341)               │
                    │  VCC GND CS RST DC MOSI SCK LED  │
                    └───┬──┬──┬──┬──┬──┬───┬───┬──────┘
                        │  │  │  │  │  │   │   │
    ┌───────────────────┼──┼──┼──┼──┼──┼───┼───┼───────────────────────┐
    │ 3V3───────────────┘  │  │  │  │  │   │   │                       │
    │ GND──────────────────┘  │  │  │  │   │   │                       │
    │ D5 (TFT_CS)─────────────┘  │  │  │   │   │                       │
    │ D4 (TFT_RST)───────────────┘  │  │   │   │                       │
    │ D2 (TFT_DC)───────────────────┘  │   │   │                       │
    │ D23 (MOSI)───────────────────────┘   │   │                       │
    │ D18 (SCK)────────────────────────────┘   │                       │
    │ D15 (TFT_BL)─────────────────────────────┘                       │
    │                                                                   │
    │                    ESP32-WROOM-32                                 │
    │                   ┌─────────────┐                                 │
    │                   │  [N4R2]     │                                 │
    │                   │  WiFi+BT    │                                 │
    │                   └─────────────┘                                 │
    │                                                                   │
    │ D12 (SD_CS)──────────┐                                           │
    │ D27 (SD_MOSI)────────┼───┐                                       │
    │ D14 (SD_CLK)─────────┼───┼───┐                                   │
    │ D13 (SD_MISO)────────┼───┼───┼───┐                               │
    │ VIN (5V)─────────────┼───┼───┼───┼───┐                           │
    │ GND──────────────────┼───┼───┼───┼───┼───┐                       │
    │                      │   │   │   │   │   │                       │
    │ TX2 (GPIO17)─────────┼───┼───┼───┼───┼───┼───┐  To 3D Printer   │
    │ RX2 (GPIO16)─────────┼───┼───┼───┼───┼───┼───┼───┐              │
    │                      │   │   │   │   │   │   │   │              │
    │ D33 (ENC_A)──────────┼───┼───┼───┼───┼───┼───┼───┼───┐ Encoder │
    │ D25 (ENC_B)──────────┼───┼───┼───┼───┼───┼───┼───┼───┼───┐     │
    │ D26 (ENC_SW)─────────┼───┼───┼───┼───┼───┼───┼───┼───┼───┼───┐ │
    │                      │   │   │   │   │   │   │   │   │   │   │ │
    │ D32 (LED)────────────┼───┼───┼───┼───┼───┼───┼───┼───┼───┼───┼─┼─→LED
    └──────────────────────┼───┼───┼───┼───┼───┼───┼───┼───┼───┼───┼─┼──┘
                           │   │   │   │   │   │   │   │   │   │   │ │
                           │   │   │   │   │   │   │   │   │   │   │ │
                    ┌──────┴───┴───┴───┴───┴───┴───┴───┴───┴───┴───┴─┴──┐
                    │  CS MOSI CLK MISO VCC GND  RX  TX   A   B  SW  DIN│
                    │  ┌──────────────────┐ ┌────────┐ ┌────────────────┤
                    │  │    SD CARD       │ │PRINTER │ │ ENCODER  │ LED│
                    │  │    MODULE        │ │ UART   │ │(optional)│    │
                    │  └──────────────────┘ └────────┘ └────────────────┘
                    └───────────────────────────────────────────────────┘
```

---

## Shopping List (What You Need)

### Already Have ✅
- [x] ESP32 DevKit with screw terminals

### Need to Buy 🛒

| Item | Price | Link |
|---|---|---|
| 2.4" TFT ILI9341 SPI | ~$5 | AliExpress/Amazon |
| MicroSD Card Module | ~$1 | AliExpress |
| MicroSD Card (8GB+) | ~$3 | Any store |
| Jumper Wires | ~$2 | Kit recommended |
| **Optional:** | | |
| Rotary Encoder EC11 | ~$1 | AliExpress |
| WS2812B LED (3pcs) | ~$1 | AliExpress |

**Total Additional Cost: ~$10-15**

---

## Flashing the Firmware

### Using PlatformIO (Recommended)

```bash
# Install PlatformIO CLI
pip install platformio

# Navigate to firmware folder
cd 3d-print-converter/firmware

# Build and upload
pio run -t upload

# Monitor serial output
pio device monitor
```

### Using Arduino IDE

1. Install ESP32 board support
2. Select "ESP32 Dev Module"
3. Install libraries:
   - TFT_eSPI
   - ArduinoJson
4. Copy pin defines from platformio.ini to User_Setup.h
5. Upload

---

## First Boot

1. **Power on** via USB
2. **Wait** for AP mode (no WiFi configured)
3. **Connect** to WiFi: "3DConverter" / Password: "12345678"
4. **Open** http://192.168.4.1
5. **Configure** your home WiFi
6. **Reboot** - it will connect to your network

---

## Troubleshooting

### TFT Shows White/Nothing
- Check all 8 wires
- Verify 3.3V power (not 5V!)
- Try swapping MOSI/MISO

### SD Card Not Detected
- Format as FAT32
- Check CS pin connection
- Try different SD card

### Can't Upload Firmware
- Hold BOOT button while pressing EN
- Release both
- Try upload again

### WiFi Not Connecting
- Check SSID/password (case sensitive)
- Move closer to router
- Try AP mode first

---

## Need Help?

The screw terminals make this super easy - no soldering required!
Just strip wire ends and screw them in.

**Wire Gauge**: 22-26 AWG works best with these terminals.

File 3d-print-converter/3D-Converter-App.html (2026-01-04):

# ⚙ 3D Print Converter

Convert CAD files to G-code for 3D printing

Connecting...

## 📤 Upload File

📁

Click or drag files here

Supports: PDF, DWG, DXF, SVG, DAT

Uploading...

## ⚙ Conversion Settings

Output Format

Scale Factor

Extrusion Height (mm)

Layer Height (mm)

Infill (%)

Server URL

Test Connection

## 📄 Conversion Jobs

No conversion jobs yet. Upload a file to get started!

## 💻 Console

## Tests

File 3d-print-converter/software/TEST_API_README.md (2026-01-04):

# API Settings Test Suite

Comprehensive test suite for the `/api/convert` endpoint that validates all 14 slicer settings parameters.

## Quick Start

### Prerequisites

1. **Start the server:**
   ```bash
   python server.py
   ```
   The server must be running on `http://localhost:8000`

2. **Run the tests:**
   ```bash
   python test_api_settings.py
   ```

### What Gets Tested

The test suite automatically creates a minimal test DXF file and validates:

1. **Backward Compatibility**: Empty settings use defaults
2. **Full Settings**: All 14 parameters provided
3. **Partial Settings**: Mix of custom and default values
4. **Bed Dimensions**: Custom bed sizes (bed_size_x/y/z)
5. **Model Processing**: center_model, repair_mesh, simplify_mesh, simplify_ratio
6. **Slicer Settings**: nozzle_diameter, print_speed, layer_height, infill_percentage, support_enabled
7. **Error Handling**: Invalid JSON and invalid parameter values
8. **Output Formats**: STL, OBJ, GCODE
9. **Edge Cases**: Minimum/maximum reasonable values

## Test Coverage

### All 14 Settings Parameters

| Parameter | Type | Default | Tested Values |
|---|---|---|---|
| `output_format` | string | "stl" | "stl", "obj", "gcode" |
| `extrusion_height` | float | 10.0 | 0.1, 15.0 |
| `scale_factor` | float | 1.0 | 0.1, 1.5 |
| `center_model` | bool | True | True, False |
| `repair_mesh` | bool | True | True, False |
| `simplify_mesh` | bool | False | True, False |
| `simplify_ratio` | float | 0.5 | 0.1, 0.5, 0.8 |
| `layer_height` | float | 0.2 | 0.05, 0.2, 0.25, 0.3 |
| `nozzle_diameter` | float | 0.4 | 0.2, 0.4, 0.6, 0.8 |
| `print_speed` | float | 50.0 | 10.0, 50.0, 70.0, 80.0, 100.0 |
| `infill_percentage` | int | 20 | 0, 20, 30, 40 |
| `support_enabled` | bool | False | True, False |
| `bed_size_x` | float | 220.0 | 220.0, 250.0, 300.0, 350.0 |
| `bed_size_y` | float | 220.0 | 220.0, 300.0, 350.0 |
| `bed_size_z` | float | 250.0 | 250.0, 400.0, 500.0 |

## Example Test Output

```
============================================================
3D ESP-Print API Settings Test Suite
============================================================
ℹ️  Base URL: http://localhost:8000
ℹ️  Endpoint: http://localhost:8000/api/convert
ℹ️  Test file: C:\...\test_data\sample.dxf

============================================================
Pre-flight Checks
============================================================
✅ Server is reachable
✅ Test file exists: C:\...\test_data\sample.dxf

============================================================
Test: Default Settings (Backward Compatibility)
============================================================
ℹ️  Testing with empty settings (backward compatibility)
ℹ️  Expected: All ConversionRequest defaults should be used
ℹ️  Status Code: 200
ℹ️  Response: {"job_id":"abc12345",...}
✅ Job created: abc12345
✅ PASSED: Empty settings accepted, defaults applied
✅ ✅ PASSED: Default Settings (Backward Compatibility)

...

============================================================
Test Results Summary
============================================================

Total Tests: 10
✅ Passed: 10

Success Rate: 100.0%

🎉 All tests passed!
```

## Test Details

### Test 1: Default Settings
- **Purpose**: Verify backward compatibility
- **Input**: Empty `settings_json` or `{}`
- **Expected**: All defaults from `ConversionRequest` model used

### Test 2: Full Settings Override
- **Purpose**: Validate all 14 parameters can be customized
- **Input**: JSON with all 14 fields
- **Expected**: Request accepted, job created

### Test 3: Partial Settings
- **Purpose**: Verify defaults merge with custom values
- **Input**: Only 3 settings (nozzle_diameter, print_speed, bed_size_x)
- **Expected**: Provided values used, others default

### Test 4: Bed Size Validation
- **Purpose**: Test custom printer dimensions
- **Input**: bed_size_x=350, bed_size_y=350, bed_size_z=500
- **Expected**: Custom dimensions accepted

### Test 5: Model Processing Settings
- **Purpose**: Validate mesh processing flags
- **Input**: center_model, repair_mesh, simplify_mesh, simplify_ratio
- **Expected**: Boolean and ratio values accepted

### Test 6: Slicer Settings
- **Purpose**: Test print quality parameters
- **Input**: nozzle_diameter, print_speed, layer_height, infill, supports
- **Expected**: All slicer params accepted

### Test 7: Invalid JSON
- **Purpose**: Error handling for malformed JSON
- **Input**: `{invalid json here}`
- **Expected**: HTTP 400 with JSON error message

### Test 8: Invalid Settings
- **Purpose**: Validation of parameter values
- **Input**: nozzle_diameter=-1.0, infill_percentage=150
- **Expected**: HTTP 400/422 for invalid values

### Test 9: Output Formats
- **Purpose**: Test all supported formats
- **Input**: output_format = "stl", "obj", "gcode"
- **Expected**: Each format accepted

### Test 10: Edge Cases
- **Purpose**: Test minimum/maximum values
- **Input**: Very small/large values within reason
- **Expected**: Edge values accepted

## API Usage Examples

### Minimal Request (Default Settings)
```python
files = {'file': open('model.dxf', 'rb')}
data = {'settings_json': '{}'}
response = requests.post('http://localhost:8000/api/convert', files=files, data=data)
```

### Full Custom Settings
```python
settings = {
    "output_format": "gcode",
    "extrusion_height": 15.0,
    "scale_factor": 1.5,
    "center_model": True,
    "repair_mesh": True,
    "simplify_mesh": False,
    "simplify_ratio": 0.5,
    "layer_height": 0.3,
    "nozzle_diameter": 0.6,
    "print_speed": 70.0,
    "infill_percentage": 30,
    "support_enabled": True,
    "bed_size_x": 300.0,
    "bed_size_y": 300.0,
    "bed_size_z": 400.0,
}

files = {'file': open('model.dxf', 'rb')}
data = {'settings_json': json.dumps(settings)}
response = requests.post('http://localhost:8000/api/convert', files=files, data=data)
```

### Partial Settings (Only Override What You Need)
```python
settings = {
    "nozzle_diameter": 0.8,
    "print_speed": 100.0,
    "support_enabled": True,
}

files = {'file': open('model.dxf', 'rb')}
data = {'settings_json': json.dumps(settings)}
response = requests.post('http://localhost:8000/api/convert', files=files, data=data)
```

## Troubleshooting

### Server Not Reachable
```
❌ Server is not reachable!
```
**Solution**: Start the server with `python server.py`

### Test File Issues
The test suite automatically creates a minimal DXF file if missing.
Location: `test_data/sample.dxf`

### Failed Tests
Check the detailed error output for each failed test. Common issues:
- Server validation rules changed
- Missing dependencies
- Network/timeout issues

## Exit Codes

- `0`: All tests passed
- `1`: One or more tests failed or error occurred

## Running Specific Tests

To run individual test functions, modify the `tests` list in `run_all_tests()`:

```python
tests = [
    ("Full Settings Override", test_full_settings),
    ("Slicer Settings", test_slicer_settings),
]
```

## Adding New Tests

1. Create a new test function following the pattern:
   ```python
   def test_my_feature():
       print_info("Testing my feature")
       settings = {...}
       response = make_api_call(settings=settings)
       validate_response(response)
       print_success("PASSED: My feature works")
   ```

2. Add to the `tests` list in `run_all_tests()`

3. Run the full suite to verify

## CI/CD Integration

Use in automated testing:

```bash
# Exit code 0 = success, 1 = failure
python test_api_settings.py
if [ $? -eq 0 ]; then
    echo "API tests passed"
else
    echo "API tests failed"
    exit 1
fi
```

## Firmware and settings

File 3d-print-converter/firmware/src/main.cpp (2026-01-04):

/**
 * CAD-to-3D Print Controller Firmware
 * =====================================
 * ESP32-S3 based controller for 3D printer file conversion
 * 
 * Features:
 * - WiFi web interface for file upload
 * - SD card storage
 * - Direct printer communication via UART
 * - TFT display status
 * - OTA updates
 * 
 * Author: Tech Sierra Solutions
 * License: MIT
 */

#include <Arduino.h>
#include <WiFi.h>
#include <WebServer.h>
#include <ESPmDNS.h>
#include <SD.h>
#include <SPI.h>
#include <TFT_eSPI.h>
#include <ArduinoJson.h>
#include <Update.h>
#include <HTTPClient.h>
#include <Preferences.h>

Preferences preferences;

// =============================================================================
// PIN DEFINITIONS - ESP32-WROOM-32 with Screw Terminals
// =============================================================================
// 
// Your board pinout (looking at USB port facing down):
// 
// LEFT SIDE:                    RIGHT SIDE:
// 3V3  |                        | VIN (5V)
// GND  |                        | GND
// D15  | ← TFT_BL               | D13 ← SD_MISO (HSPI)
// D2   | ← TFT_DC               | D12 ← SD_CS
// D4   | ← TFT_RST              | D14 ← SD_CLK (HSPI)
// RX2  | ← (GPIO16)             | D27 ← SD_MOSI (HSPI)
// TX2  | ← (GPIO17)             | D26 ← ENC_SW (button)
// D5   | ← TFT_CS               | D25 ← ENC_B
// D18  | ← TFT_SCK (VSPI)       | D33 ← ENC_A
// D19  | ← TFT_MISO (VSPI)      | D32 ← LED_DATA
// D21  | ← (I2C SDA)            | D35 ← (input only)
// D3   | ← (RX0 - programming)  | D34 ← (input only)
// D1   | ← (TX0 - programming)  | VN
// D22  | ← (I2C SCL)            | VP
// D23  | ← TFT_MOSI (VSPI)      | EN
//
// =============================================================================

// SD Card (HSPI - separate from TFT)
#define SD_CS       12
#define SD_MOSI     27
#define SD_MISO     13
#define SD_SCK      14

// TFT Display (VSPI) - configured via TFT_eSPI library in platformio.ini
// TFT_CS=5, TFT_DC=2, TFT_RST=4, TFT_BL=15
// TFT_MOSI=23, TFT_MISO=19, TFT_SCLK=18

// Printer UART (UART2)
#define PRINTER_TX  17  // TX2
#define PRINTER_RX  16  // RX2
#define PRINTER_BAUD 115200

// Rotary Encoder
#define ENC_A       33
#define ENC_B       25
#define ENC_SW      26

// Status LED (WS2812B single or strip)
#define LED_PIN     32
#define NUM_LEDS    3

// Buzzer (optional)
#define BUZZER_PIN  -1  // Not connected by default

// TFT Backlight
#define TFT_BL_PIN  15

// =============================================================================
// GLOBAL OBJECTS
// =============================================================================

WebServer server(80);
TFT_eSPI tft = TFT_eSPI();
HardwareSerial PrinterSerial(1);

// =============================================================================
// CONFIGURATION
// =============================================================================

struct Config {
    char wifi_ssid[32] = "";
    char wifi_pass[64] = "";
    char device_name[32] = "3DConverter";
    char server_url[128] = "";  // URL of companion server
    int printer_baud = 115200;
    bool auto_start_print = false;
} config;

// =============================================================================
// STATE
// =============================================================================

enum SystemState {
    STATE_INIT,
    STATE_WIFI_CONNECTING,
    STATE_WIFI_AP_MODE,
    STATE_IDLE,
    STATE_UPLOADING,
    STATE_CONVERTING,
    STATE_PRINTING,
    STATE_ERROR
};

struct SystemStatus {
    SystemState state = STATE_INIT;
    String current_file = "";
    int print_progress = 0;
    String error_message = "";
    bool sd_card_present = false;
    bool printer_connected = false;
    IPAddress ip_address;
} status;

// File queue
#define MAX_QUEUE_SIZE 10
String file_queue[MAX_QUEUE_SIZE];
int queue_head = 0;
int queue_tail = 0;

// =============================================================================
// DISPLAY FUNCTIONS
// =============================================================================

void display_init() {
    tft.init();
    tft.setRotation(1);
    tft.fillScreen(TFT_BLACK);
    tft.setTextColor(TFT_WHITE, TFT_BLACK);
    tft.setTextSize(2);
}

void display_status() {
    tft.fillScreen(TFT_BLACK);
    tft.setCursor(10, 10);
    tft.setTextColor(TFT_CYAN);
    tft.println("3D Print Converter");
    
    tft.setTextColor(TFT_WHITE);
    tft.setCursor(10, 40);
    
    switch (status.state) {
        case STATE_INIT:
            tft.println("Initializing...");
            break;
        case STATE_WIFI_CONNECTING:
            tft.println("Connecting WiFi...");
            break;
        case STATE_WIFI_AP_MODE:
            tft.println("AP Mode: " + String(config.device_name));
            tft.setCursor(10, 60);
            tft.println("IP: 192.168.4.1");
            break;
        case STATE_IDLE:
            tft.println("Ready");
            tft.setCursor(10, 60);
            tft.println("IP: " + status.ip_address.toString());
            break;
        case STATE_UPLOADING:
            tft.println("Uploading...");
            tft.setCursor(10, 60);
            tft.println(status.current_file);
            break;
        case STATE_CONVERTING:
            tft.setTextColor(TFT_YELLOW);
            tft.println("Converting...");
            tft.setCursor(10, 60);
            tft.println(status.current_file);
            break;
        case STATE_PRINTING:
            tft.setTextColor(TFT_GREEN);
            tft.println("Printing: " + String(status.print_progress) + "%");
            tft.setCursor(10, 60);
            tft.println(status.current_file);
            // Draw progress bar
            tft.drawRect(10, 80, 200, 20, TFT_WHITE);
            tft.fillRect(12, 82, (196 * status.print_progress) / 100, 16, TFT_GREEN);
            break;
        case STATE_ERROR:
            tft.setTextColor(TFT_RED);
            tft.println("ERROR:");
            tft.setCursor(10, 60);
            tft.println(status.error_message);
            break;
    }
    
    // Status indicators
    tft.setCursor(10, 120);
    tft.setTextSize(1);
    tft.setTextColor(status.sd_card_present ? TFT_GREEN : TFT_RED);
    tft.print("SD:");
    tft.print(status.sd_card_present ? "OK " : "NO ");
    
    tft.setTextColor(status.printer_connected ? TFT_GREEN : TFT_RED);
    tft.print("Printer:");
    tft.println(status.printer_connected ? "OK" : "NO");
}

// =============================================================================
// SD CARD FUNCTIONS
// =============================================================================

bool sd_init() {
    // Use HSPI for SD card (separate from TFT which uses VSPI)
    SPIClass *hspi = new SPIClass(HSPI);
    hspi->begin(SD_SCK, SD_MISO, SD_MOSI, SD_CS);
    
    if (!SD.begin(SD_CS, *hspi)) {
        Serial.println("SD Card mount failed");
        status.sd_card_present = false;
        return false;
    }
    
    uint8_t cardType = SD.cardType();
    if (cardType == CARD_NONE) {
        Serial.println("No SD card attached");
        status.sd_card_present = false;
        return false;
    }
    
    Serial.printf("SD Card Type: %s\n", 
        cardType == CARD_MMC ? "MMC" :
        cardType == CARD_SD ? "SDSC" :
        cardType == CARD_SDHC ? "SDHC" : "UNKNOWN");
    
    Serial.printf("SD Card Size: %lluMB\n", SD.cardSize() / (1024 * 1024));
    
    // Create directories
    if (!SD.exists("/uploads")) SD.mkdir("/uploads");
    if (!SD.exists("/converted")) SD.mkdir("/converted");
    if (!SD.exists("/gcode")) SD.mkdir("/gcode");
    
    status.sd_card_present = true;
    return true;
}

String get_file_list(const char* path) {
    StaticJsonDocument<4096> doc;
    JsonArray files = doc.createNestedArray("files");
    
    File root = SD.open(path);
    if (!root || !root.isDirectory()) {
        return "[]";
    }
    
    File file = root.openNextFile();
    while (file) {
        JsonObject f = files.createNestedObject();
        f["name"] = String(file.name());
        f["size"] = file.size();
        f["is_dir"] = file.isDirectory();
        file = root.openNextFile();
    }
    
    String output;
    serializeJson(doc, output);
    return output;
}

// =============================================================================
// PRINTER COMMUNICATION
// =============================================================================

void printer_init() {
    PrinterSerial.begin(config.printer_baud, SERIAL_8N1, PRINTER_RX, PRINTER_TX);
    Serial.println("Printer UART initialized");
}

bool printer_check_connection() {
    PrinterSerial.println("M115");  // Get firmware info
    
    unsigned long start = millis();
    while (millis() - start < 2000) {
        if (PrinterSerial.available()) {
            String response = PrinterSerial.readStringUntil('\n');
            if (response.indexOf("FIRMWARE") >= 0 || response.indexOf("ok") >= 0) {
                status.printer_connected = true;
                return true;
            }
        }
        delay(10);
    }
    
    status.printer_connected = false;
    return false;
}

void printer_send_gcode(const String& gcode) {
    PrinterSerial.println(gcode);
}

String printer_wait_response(unsigned long timeout = 5000) {
    unsigned long start = millis();
    String response = "";
    
    while (millis() - start < timeout) {
        if (PrinterSerial.available()) {
            char c = PrinterSerial.read();
            response += c;
            if (c == '\n' && response.indexOf("ok") >= 0) {
                break;
            }
        }
        delay(1);
    }
    
    return response;
}

bool printer_stream_file(const String& filepath) {
    File file = SD.open(filepath);
    if (!file) {
        status.error_message = "Failed to open: " + filepath;
        status.state = STATE_ERROR;
        return false;
    }
    
    status.state = STATE_PRINTING;
    status.current_file = filepath;
    status.print_progress = 0;
    
    long file_size = file.size();
    long bytes_sent = 0;
    
    while (file.available()) {
        String line = file.readStringUntil('\n');
        line.trim();
        
        // Skip comments and empty lines
        if (line.length() == 0 || line.startsWith(";")) {
            continue;
        }
        
        // Send line to printer
        printer_send_gcode(line);
        
        // Wait for acknowledgment
        String response = printer_wait_response();
        if (response.indexOf("ok") < 0) {
            Serial.println("Printer error: " + response);
        }
        
        // Update progress
        bytes_sent += line.length();
        status.print_progress = (bytes_sent * 100) / file_size;
        
        // Update display periodically
        if (status.print_progress % 5 == 0) {
            display_status();
        }
        
        yield();  // Allow other tasks
    }
    
    file.close();
    status.state = STATE_IDLE;
    status.print_progress = 100;
    
    return true;
}

// =============================================================================
// FILE CONVERSION
// =============================================================================

bool convert_file_local(const String& input_path, const String& output_path) {
    // Basic local conversion for simple DXF files
    // For complex conversions, use the companion server
    
    File input = SD.open(input_path);
    if (!input) {
        return false;
    }
    
    // Read file extension
    String ext = input_path.substring(input_path.lastIndexOf('.'));
    ext.toLowerCase();
    
    if (ext == ".gcode" || ext == ".gco") {
        // Already G-code, just copy
        File output = SD.open(output_path, FILE_WRITE);
        if (!output) {
            input.close();
            return false;
        }
        
        while (input.available()) {
            output.write(input.read());
        }
        
        output.close();
        input.close();
        return true;
    }
    
    // For other formats, we need the companion server
    input.close();
    return false;
}

bool convert_file_server(const String& input_path) {
    if (strlen(config.server_url) == 0) {
        status.error_message = "No server configured";
        return false;
    }
    
    status.state = STATE_CONVERTING;
    status.current_file = input_path;
    display_status();
    
    // Read file
    File file = SD.open(input_path);
    if (!file) {
        status.error_message = "Failed to open file";
        status.state = STATE_ERROR;
        return false;
    }
    
    HTTPClient http;
    String url = String(config.server_url) + "/api/convert";
    
    http.begin(url);
    http.addHeader("Content-Type", "application/octet-stream");
    http.addHeader("X-Filename", input_path.substring(input_path.lastIndexOf('/') + 1));
    
    // Stream file to server
    int httpCode = http.sendRequest("POST", &file, file.size());
    file.close();
    
    if (httpCode != 200) {
        status.error_message = "Server error: " + String(httpCode);
        status.state = STATE_ERROR;
        http.end();
        return false;
    }
    
    // Get response (G-code)
    String output_path = "/gcode/" + input_path.substring(
        input_path.lastIndexOf('/') + 1,
        input_path.lastIndexOf('.')
    ) + ".gcode";
    
    File output = SD.open(output_path, FILE_WRITE);
    if (!output) {
        status.error_message = "Failed to create output";
        status.state = STATE_ERROR;
        http.end();
        return false;
    }
    
    // Stream response to SD card
    WiFiClient* stream = http.getStreamPtr();
    uint8_t buffer[512];
    
    while (http.connected() && stream->available()) {
        size_t bytes = stream->readBytes(buffer, sizeof(buffer));
        output.write(buffer, bytes);
    }
    
    output.close();
    http.end();
    
    status.state = STATE_IDLE;
    return true;
}

// =============================================================================
// WEB SERVER HANDLERS
// =============================================================================

const char INDEX_HTML[] PROGMEM = R"rawliteral(
<!DOCTYPE html>
<html>
<head>
    <title>3D Print Converter</title>
    <meta charset="UTF-8">
    <meta name="viewport" content="width=device-width, initial-scale=1">
    <style>
        * { box-sizing: border-box; font-family: -apple-system, BlinkMacSystemFont, sans-serif; }
        body { margin: 0; padding: 20px; background: #1a1a2e; color: #eee; }
        .container { max-width: 800px; margin: 0 auto; }
        h1 { color: #00d4ff; }
        .card { background: #16213e; border-radius: 10px; padding: 20px; margin-bottom: 20px; }
        .status { display: flex; gap: 20px; flex-wrap: wrap; }
        .status-item { flex: 1; min-width: 150px; }
        .status-label { color: #888; font-size: 12px; }
        .status-value { font-size: 24px; font-weight: bold; }
        .ok { color: #4caf50; }
        .error { color: #f44336; }
        .warning { color: #ff9800; }
        .upload-area { 
            border: 2px dashed #00d4ff; 
            border-radius: 10px; 
            padding: 40px; 
            text-align: center; 
            cursor: pointer;
            transition: background 0.3s;
        }
        .upload-area:hover { background: rgba(0,212,255,0.1); }
        .upload-area.dragover { background: rgba(0,212,255,0.2); }
        input[type="file"] { display: none; }
        .btn { 
            background: #00d4ff; 
            color: #000; 
            border: none; 
            padding: 12px 24px; 
            border-radius: 5px; 
            cursor: pointer;
            font-weight: bold;
            margin: 5px;
        }
        .btn:hover { background: #00b8e6; }
        .btn.secondary { background: #333; color: #fff; }
        .file-list { max-height: 300px; overflow-y: auto; }
        .file-item { 
            display: flex; 
            justify-content: space-between; 
            align-items: center;
            padding: 10px; 
            border-bottom: 1px solid #333; 
        }
        .file-item:hover { background: rgba(255,255,255,0.05); }
        .progress-bar { 
            height: 4px; 
            background: #333; 
            border-radius: 2px; 
            overflow: hidden;
            margin-top: 10px;
        }
        .progress-fill { 
            height: 100%; 
            background: #00d4ff; 
            width: 0%; 
            transition: width 0.3s;
        }
        .tabs { display: flex; gap: 10px; margin-bottom: 20px; }
        .tab { 
            padding: 10px 20px; 
            background: #16213e; 
            border-radius: 5px; 
            cursor: pointer;
        }
        .tab.active { background: #00d4ff; color: #000; }
        .console {
            background: #000;
            color: #0f0;
            font-family: monospace;
            padding: 15px;
            border-radius: 5px;
            height: 200px;
            overflow-y: auto;
        }
        /* Upload Animation */
        .upload-progress { display: none; text-align: center; padding: 30px; }
        .upload-progress.active { display: block; }
        .upload-stages { display: flex; justify-content: space-around; margin: 20px 0; }
        .stage { text-align: center; opacity: 0.3; transition: all 0.3s; }
        .stage.active { opacity: 1; }
        .stage.done { opacity: 1; color: #4caf50; }
        .stage-icon { font-size: 40px; margin-bottom: 10px; }
        .stage-label { font-size: 12px; color: #888; }
        .spinner {
            width: 50px; height: 50px;
            border: 4px solid #333;
            border-top: 4px solid #00d4ff;
            border-radius: 50%;
            animation: spin 1s linear infinite;
            margin: 20px auto;
        }
        @keyframes spin { 0% { transform: rotate(0deg); } 100% { transform: rotate(360deg); } }
        .upload-message { font-size: 18px; margin: 15px 0; }
        /* WiFi Instructions */
        .wifi-steps { background: #0d1117; padding: 15px; border-radius: 8px; margin: 15px 0; }
        .wifi-steps ol { margin: 0; padding-left: 20px; }
        .wifi-steps li { margin: 8px 0; line-height: 1.6; }
        .highlight { background: #00d4ff; color: #000; padding: 2px 6px; border-radius: 3px; font-family: monospace; }
        .collapsible { cursor: pointer; padding: 10px; background: #0d1117; border-radius: 5px; margin: 10px 0; }
        .collapsible:hover { background: #161b22; }
        .collapsible-content { display: none; padding: 15px; background: #0d1117; border-radius: 0 0 5px 5px; margin-top: -10px; }
        .collapsible-content.show { display: block; }
    </style>
</head>
<body>
    <div class="container">
        <h1>&#9881; 3D Print Converter</h1>
        
        <div class="card">
            <h3>System Status</h3>
            <div class="status">
                <div class="status-item">
                    <div class="status-label">WiFi</div>
                    <div class="status-value ok" id="wifi-status">Connected</div>
                </div>
                <div class="status-item">
                    <div class="status-label">SD Card</div>
                    <div class="status-value" id="sd-status">-</div>
                </div>
                <div class="status-item">
                    <div class="status-label">Printer</div>
                    <div class="status-value" id="printer-status">-</div>
                </div>
                <div class="status-item">
                    <div class="status-label">State</div>
                    <div class="status-value" id="state">-</div>
                </div>
            </div>
            <div class="progress-bar">
                <div class="progress-fill" id="progress"></div>
            </div>
        </div>

        <div class="card" id="getting-started">
            <h3>&#128218; Getting Started Guide</h3>
            <div style="line-height:1.8">
                <p><strong>How This System Works:</strong></p>
                <ol style="margin-left:20px">
                    <li><strong>Upload CAD Files</strong> - Drop DWG, DXF, PDF, or other CAD files below</li>
                    <li><strong>Convert to G-code</strong> - Files are sent to your PC server for conversion</li>
                    <li><strong>Print Directly</strong> - G-code streams to your 3D printer via serial</li>
                </ol>

                <p style="margin-top:15px"><strong>Setup Checklist:</strong></p>
                <ul style="margin-left:20px;list-style:none">
                    <li id="check-wifi">&#9989; WiFi Connected</li>
                    <li id="check-sd">&#10060; SD Card - <em>Optional for file storage</em></li>
                    <li id="check-server">&#9744; Companion Server - <em>Set URL in Settings below</em></li>
                    <li id="check-printer">&#9744; 3D Printer - <em>Connect via TX2/RX2 pins</em></li>
                </ul>
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
void loop() {
    server.handleClient();
    
    // Periodic tasks
    static unsigned long last_status_update = 0;
    if (millis() - last_status_update > 5000) {
        last_status_update = millis();
        
        // Check printer connection
        if (status.state == STATE_IDLE) {
            printer_check_connection();
        }
        
        // Update display
        display_status();
    }
    
    // Handle encoder input (if needed)
    // ... encoder handling code ...
    
    delay(1);
}

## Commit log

2026-01-04 Add complete 3D Print Converter system
    - ESP32-S3 firmware with web interface, TFT display, SD card support
    - Python conversion engine (DWG/DXF/PDF/SVG → STL/G-code)
    - FastAPI server with async job queue
    - Portable app and Windows executable builds
    - OpenSCAD enclosure designs with STL exports
    - Test suite and sample data
    [controller_base.scad, controller_base.stl, controller_base_standalone.scad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]
2026-01-04 Add comprehensive README and MIT license
    - Full project documentation with architecture diagrams
    - Quick start guide and API reference
    - Hardware BOM and wiring instructions
    - Troubleshooting section
    - MIT license
